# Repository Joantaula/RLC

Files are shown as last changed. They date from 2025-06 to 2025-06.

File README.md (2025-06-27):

# Cointer

Sistema clasificador con detección de falsificaciones y dispensado óptimo de cambio. Desarrollado como proyecto para la asignatura de Ingeniería Informática, Robótica.

---

## 📋 Descripción

Cointer es una solución robótica integral diseñada para automatizar el proceso de recepción y devolución de monedas en nuestros hogares a modo de hucha y en sistemas de pago físicos. El robot está formado por un módulo de detección por visión y pesaje, que identifica hasta ocho tipos de moneda (2 €, 1 €, 0,50 €, 0,20 €, 0,10 €, 0,05 €, 0,02 € y 0,01 €) determina si se trata de una moneda de euro o no. En caso negativo la descarta y en caso de ser una moneda de euro auténtica, la clasifica automáticamente segun su valor. Seguidamente, calcula en tiempo real el importe depositado. En caso de que el usuario solicite la extracción de un importe, un algoritmo voraz determina la combinación óptima de monedas para devolver el cambio exacto; si no es posible, se recurre a una rutina de respaldo que ajusta la selección.

El hardware integra una Raspberry Pi para la parte de visión y control de alto nivel, junto con un Arduino y hasta ocho motores paso a paso (uno por denominación) manejados por drivers A4988 o ULN2003 para el dispensado mecánico. La parte de software está estructurada en módulos: Monedero, para la lógica de cálculo y gestión de inventario de monedas, y Motores, para el control preciso de cada actuador. Además, un teclado matricial y una pantalla LCD permiten la interacción con el usuario, mostrando saldos, importes y estados del proceso.

Este proyecto combina conocimientos de electrónica, mecánica, visión artificial y diseño de algoritmos para ofrecer un sistema escalable, modular y fiable, ideal para administrar pequeños ahorros en el hogar y aplicaciones en máquinas expendedoras, kioscos de autoservicio y cualquier entorno que requiera gestión automática de monedas.

---

## 📊 Lista de componentes y presupuesto

| Componente | P. unitario (€) | Cantidad | Subtotal (€) |
| --- | ---:| ---:| ---:|
| Raspberry Pi 4 Model B 8 GB RAM | 88,55 | 1 | 88,55 |
| Cámara Raspberry Pi v2 – 8 Megapixels | 19,95 | 1 | 19,95 |
| Pantalla LCD 16×2 con módulo I²C | 7,95 | 1 | 7,95 |
| Motor paso a paso 28BYJ-48 (5 V) con driver ULN2003 | 2,95 | 10 | 29,50 |
| Arduino Mega2560 | 43,75 | 1 | 43,75 |
| Teclado matricial de 16 botones | 5,50 | 1 | 5,50 |
| Memoria MicroSD Kingston 128 GB (Clase 10) | 10,70 | 1 | 10,70 |
| Célula de carga 5 kg con amplificador HX711 | 4,10 | 1 | 4,10 |
| Fuente alimentación 4 salidas 5/12/−5/−12 125 W | 38,50 | 1 | 38,50 |
| **Total** | | | **248,5** |

> Consulta `Cointer_RLP_Budget 2.xlsx` para detalles de proveedores, enlaces y fechas de pedido.

---

## ⚙️ Características

- **Lectura de saldo**: muestra por Serial el total de euros disponible.  
- **Entrada de importe**: teclado matricial 4×4 para introducir cantidades con coma (‘*’).  
- **Algoritmo de cambio**: voraz con respaldo y reversión si no hay cambio exacto.  
- **Dispensado**: control de hasta 8 motores paso a paso (uno por cada denominación).  
- **Modularidad**: separa lógica de cálculo de cambio (Monedero) y control de motores (Motores).
- **Escalabilidad**: fácil adaptación a nuevas denominaciones o mecanismos de dispensado mediante configuración de Monedero y mapeo de motores.

---

## 📦 Estructura de ficheros

```text
/  
├─ designs
│   ├─ disseny3D.pdf
│   ├─ disseny3D.step
│   └─ esquema_conexiones.png
├─images
│   ├─ ....
├─ src
│   ├─ arduino
│   │   ├─ lcd.h
│   │   ├─ numpad.h 
│   │   ├─ Monedero.h
│   │   ├─ Monedero.cpp       
│   │   ├─ Motores.h          
│   │   ├─ Motores.cpp        
│   │   ├─ ControlDineroCompleto.ino
|   |   ├─ Testers
|   |   |    ├─ (Código testing componentes)
|   ├─ raspberry
|   |   ├─ Neural_Network
|   |   |   ├─ classify_image.py
|   |   |   ├─ preprocess_image.py
|   |   |   ├─ train_model.py
|   |   ├─  Testers
|   |   |   ├─ (Código testing componentes)
|   |   ├─ config.py
|   |   ├─ main.py
|   |   ├─ motor.py
|   |   ├─ sensor_peso.py
|   |   └─ vision.py
├─ Cointer_RLP_Budget 2.xlsx   # Presupuesto detallado
└─ README.md       
```

## 🛠️ Instalación y compilación
Abre el proyecto en el Arduino IDE (y en VS Code/Thonny para Pi, si lo usas).

Instala la librería Keypad desde el Gestor de Bibliotecas.

Copia los archivos .h, .cpp, el .ino y el .xlsx en la misma carpeta de sketch/repositorio.

Selecciona placa y puerto correctos.

Compila y sube al Arduino; en el Pi, lanza el script de visión si corresponde.

## 📚 Referencias y guías

(Todos los enlaces revisados antes del 25/06/2025)

Para facilitar el montaje y uso de los componentes hardware, se recomienda consultar las siguientes guías y documentación oficiales: [Especificaciones de la Raspberry Pi 4 Model B 8 GB RAM](https://www.raspberrypi.com/products/raspberry-pi-4-model-b/specifications/), [SparkFun HX711 Load Cell Amplifier Hookup Guide](https://learn.sparkfun.com/tutorials/load-cell-amplifier-hx711-breakout-hookup-guide/all), [Documentación de la cámara Raspberry Pi Camera Module V2](https://www.raspberrypi.com/documentation/accessories/camera.html), [Tutorial Arduino LCD 20×4 I²C](https://arduinogetstarted.com/tutorials/arduino-lcd-20x4), [Tutorial 28BYJ-48 + ULN2003](https://m.youtube.com/watch?v=avrdDZD7qEQ), [Especificaciones NEMA 8 en STEPPERONLINE](https://www.omc-stepperonline.com/nema-8-stepper-motor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), [Datasheet Luxeon III (LED RGB 3 W) en Farnell](https://www.farnell.com/datasheets/38512.pdf), [SparkFun Qwiic Keypad Hookup Guide](https://learn.sparkfun.com/tutorials/qwiic-keypad-hookup-guide/all), [Documentación Raspberry Pi Pico](https://www.raspberrypi.com/documentation/microcontrollers/raspberry-pi-pico.html), [Datasheet microSDHC/microSDXC Class 10 UHS-I (128 GB) de Kingston](https://www.kingston.com/datasheets/SDC10G2_us.pdf), [A4988 Stepper Motor Driver Carrier – Pololu #1182](https://www.pololu.com/product/1182) y [MPB125-4350G AC-DC 4 salidas 125 W de Bel Fuse](https://www.belfuse.com/products/power-supplies/ac-dc-converters/mpb125-4350g).

# Estructura del robot
## Tambor
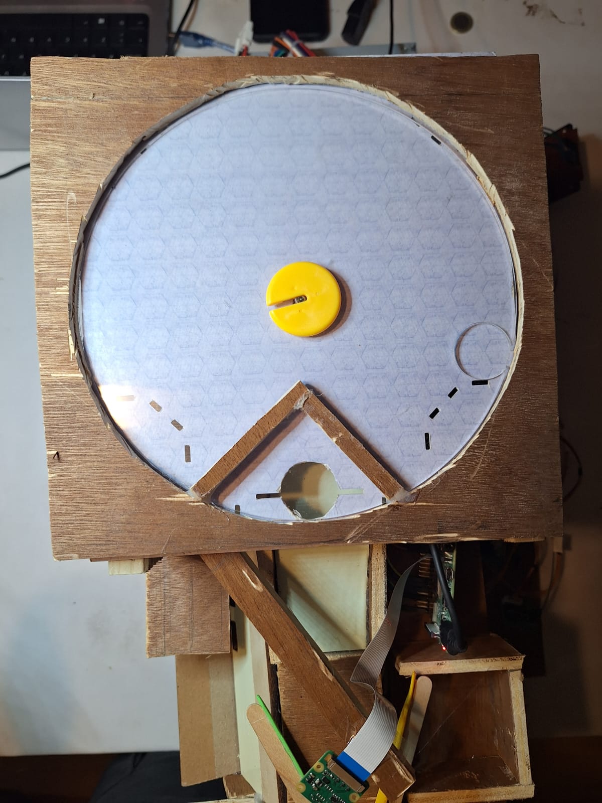
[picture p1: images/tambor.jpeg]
Tambor

Esta es la parte donde se inicializa el funcionamiento del robot. Se colocan el conjunto de monedas a clasificar encima del tambor, este tiene un funcionamiento parecido al de un tambor alimentario, que al rotar, empuja las monedas hacia las paredes de manera que una de las monedas entra en la muesca (de diámetro y altua de una moneda de 2 euros) en el tambor. Una vez da la vuelta es la única moneda capaz de sobrepasar las paredes de madera que delimitan el abujero y cayendo en este y deslizandose por la rampa hasta el sensor de peso.
## Discriminador
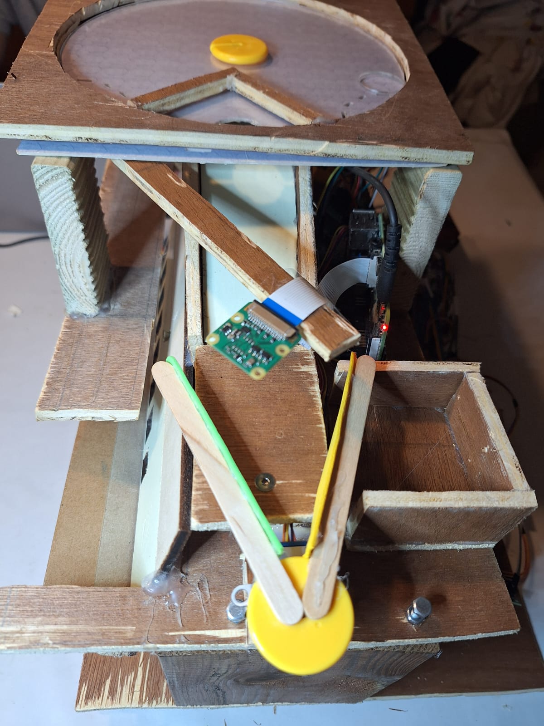
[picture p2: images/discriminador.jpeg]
Discriminador

Una vez la moneda ha caído por la rampa y se situa en el sensor de peso, la raspberry ordena la detención del motor paso a paso del tambor (usa multithreading, ya que va rotando el motor y va midiendo si hay una variación de peso en el sensor) y mediante la celula de carga se obtiene el peso del elemento que ha sido seleccionado y junto a la imagen capturada de la moneda en este momento mediante la camara de la raspberry, se procede a disriminar usando la red neuronal el objeto (moneda de euro o no). Una vez clasificado, se ordena al otro motor paso a paso a rotar para retirar la moneda del sensor de peso (si la rotación es en sentido horario, se descarta el objeto y se almacena en un pequeño compartimento al lado del sensor de peso. Rotación en sentido antihorario, la moneda cae en la rampa clasificadora) y seguir con el resto de clasificación.
## Clasificador
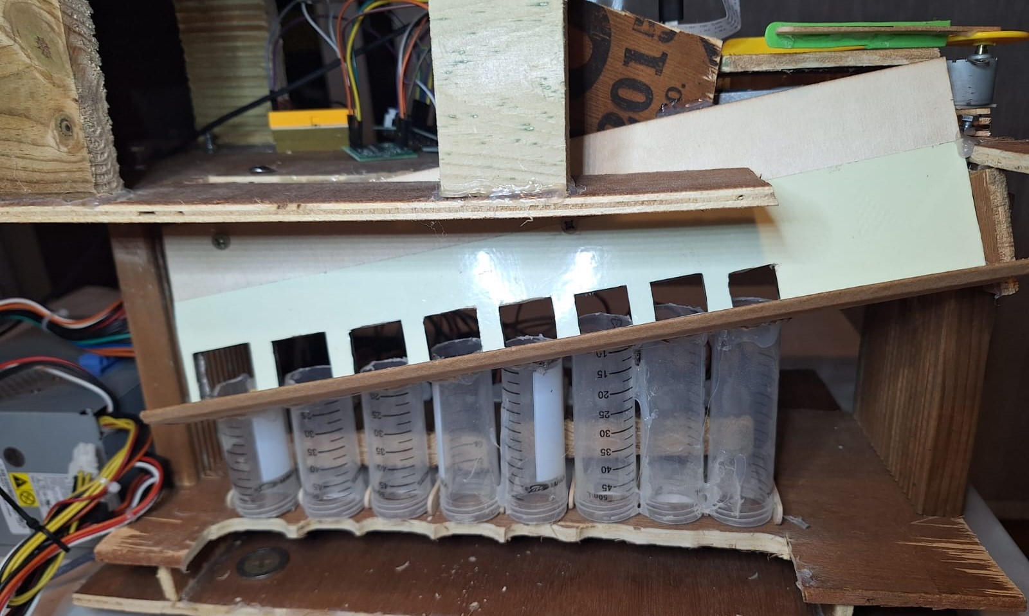
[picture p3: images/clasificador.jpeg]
Clasificador

Una vez sabemos que el objeto seleccionado es una moneda, esta cae sobre la rampa de clasificacion, rodando sobre el canto, y gracias a la inclinación tanto en eje x como en eje y, esta cojerá inercia y caerá en su respectivo compartimento, cayendo en el primer abujero que quepa. Teniendo en cuenta que para hacer esto los compartimentos se ordenan de menor a mayor diametro de la moneda (En orden ascendente de derecha a izquierda se ordenan: 1,2,10,5,20cnts,1€,50cnts,2€).
## Almacenamiento
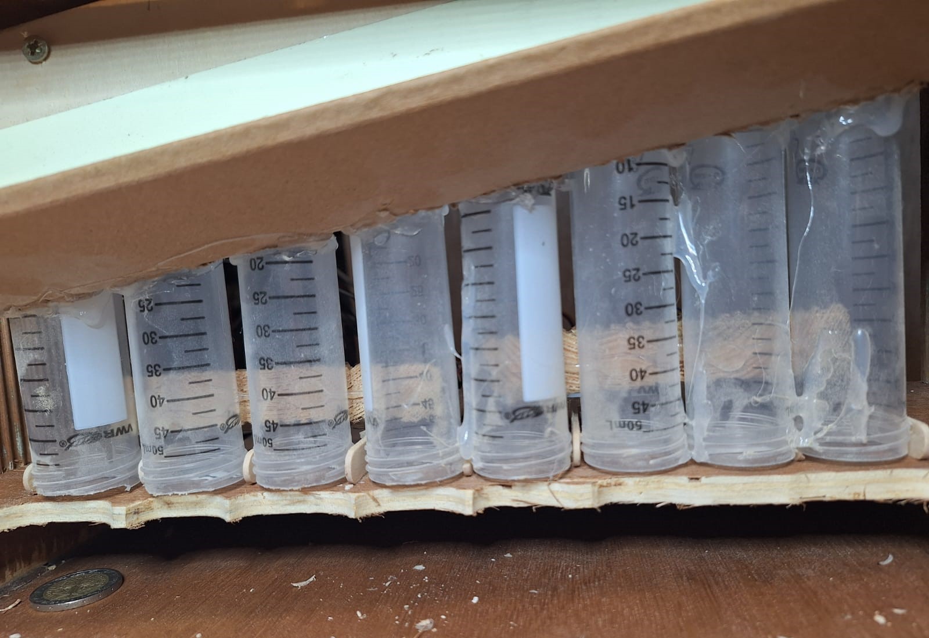
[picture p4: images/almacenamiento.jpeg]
Almacenamiento

A esta altura, la moneda ya habrá sido almacenada en el compartimento correspondiente, en cada uno de estos se admite un gran número de monedas que serán extraídas mediante los motores paso a paso, uno para cada tubo.
## Bielas
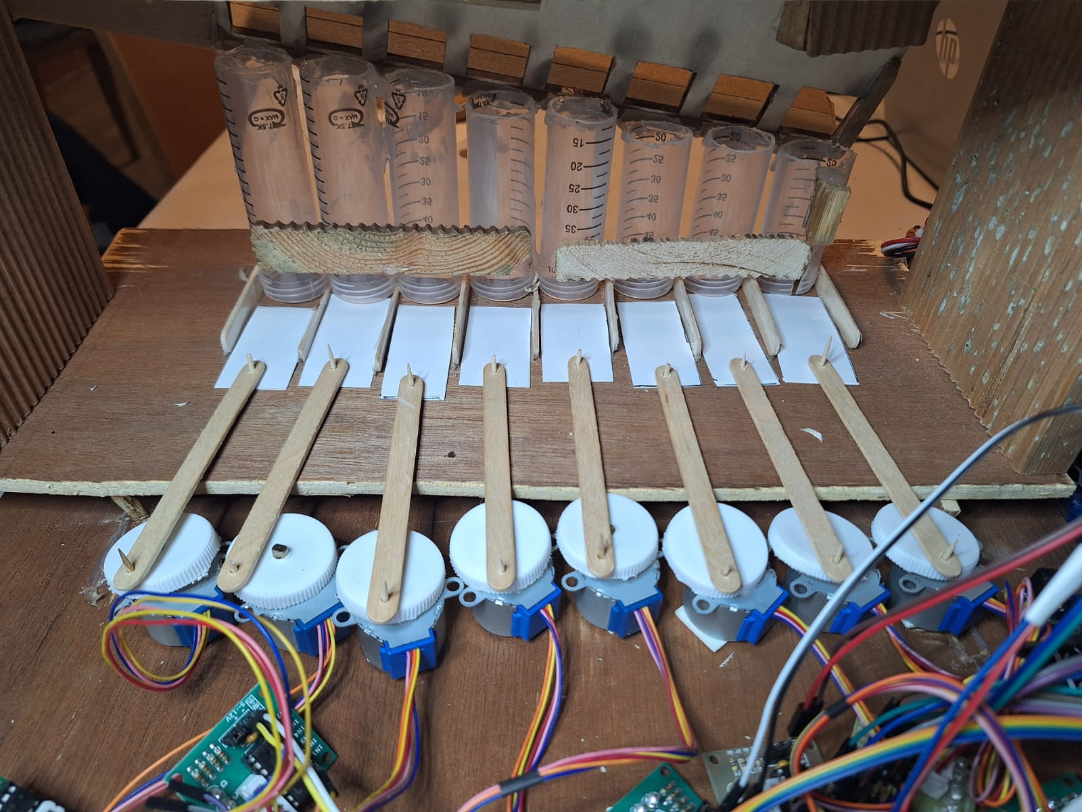
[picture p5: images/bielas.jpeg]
Bielas

Para dar pie a la extracción de una cantidad concreta de monedas, usaremos un arduino que se encargará de controlar los 8 motores paso a paso (1 para cada tipo de moneda). Cada motor paso a paso tiene unido una pieza que replica el funcionamiento de una biela manivela, de manera que cuando pedimos la extracción de una o varias monedas, el motor o motores paso a paso correspondientes emujan las monedas. Además con la separación que hay entre cada compartimento y el soporte permite que al empujar con la biela solo salga una moneda aún que en el compartimento se encuentre más de una.
## Numpad
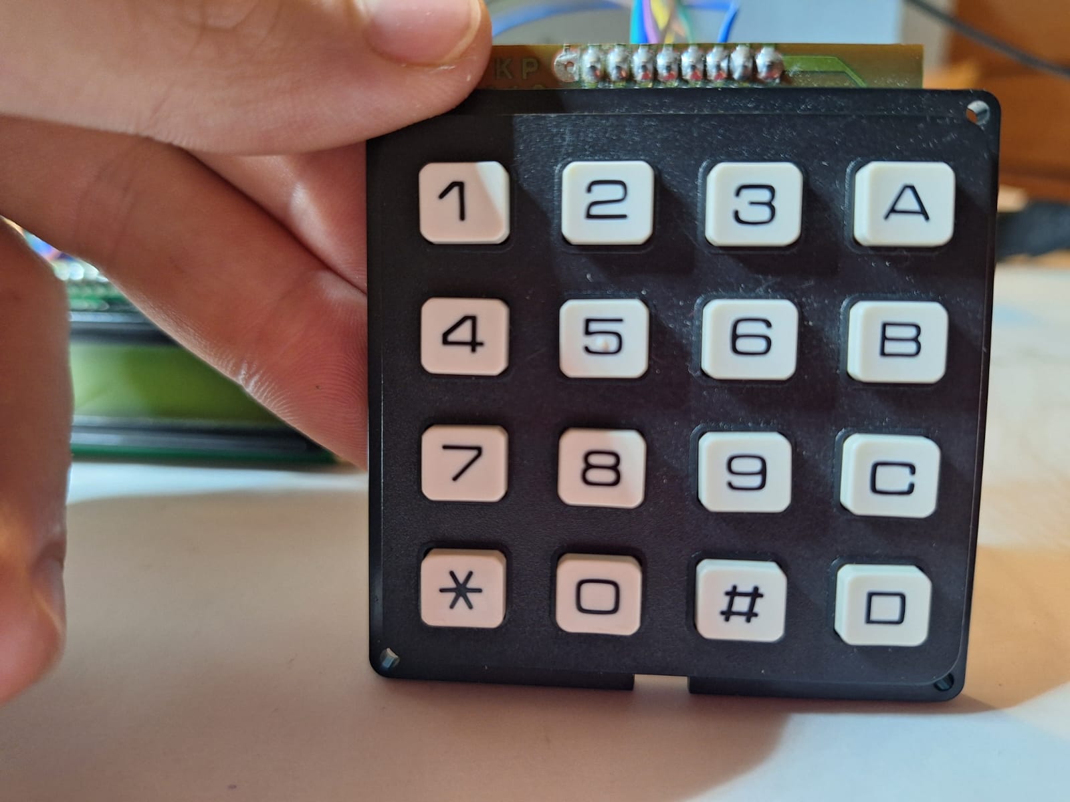
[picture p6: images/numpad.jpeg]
Numpad

Este es el componente mediante el que solicitaremos la extracción de un importe concreto (esta conectado al arduino). En el caso del numpad usado, antes de extraer un importe deberemos de presionar la tecla "#" y la coma se representa con el caracter "*". Una vez hemos indicado el importe deseado, presionaremos el caracter "C" para confirmar la dispensación. En caso de no querer confirmar la extracción del importe presionarmeos "B" para volver al menú inicial.
## Pantalla
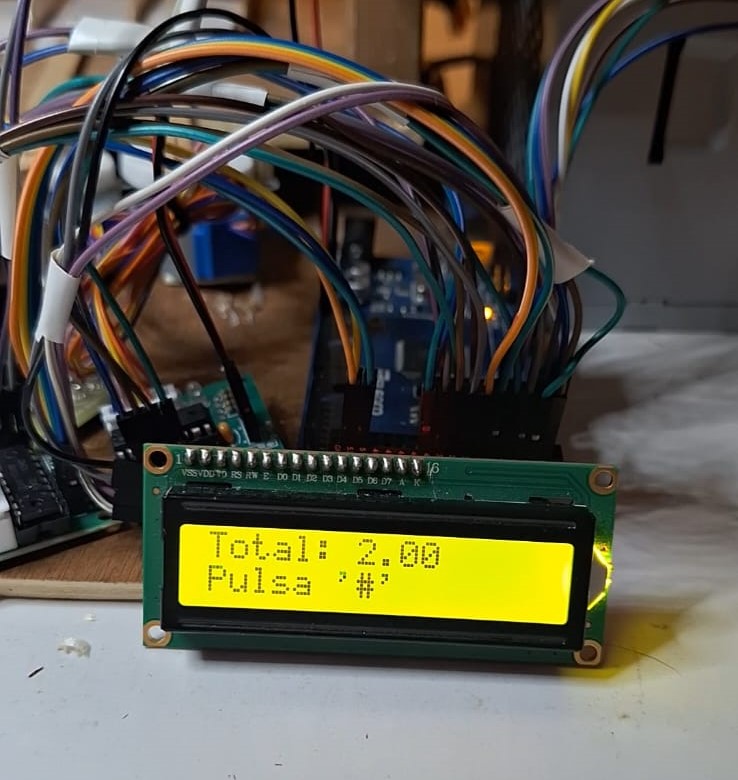
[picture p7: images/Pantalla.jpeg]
Pantalla

Componente encargado de mostrar por pantalla de forma visual al usuario el contenido y funcionamiento del robot. Inicialmente podremos observar el valor de monedas que se encuentra almacenado (este valor se modifica al clasficar una moneda como moneda de euro gracias a la camara y sensor de peso, este nuevo valor se lo comunica la raspberry al arduino). También podemos ver cuando se esta haciendo una extracció o cuando se intenta hacer de forma errónea, teniendo sus respectivos errores explicativos (demasiados decimales, mas de una coma, valor de extracción nulo, cantidad insuficiente).

# Red Neuronal
Este proyecto utiliza una red neuronal convolucional (CNN) entrenada para clasificar monedas entre 9 categorías:

- `1cent`, `2cent`, `5cent`, `10cent`, `20cent`, `50cent`, `1eur`, `2eur`, `no_coin`

### 📌 Propósito

La red neuronal se encarga de **clasificar automáticamente** la moneda capturada por la cámara al caer en el compartimento de pesaje. Según su clase, el sistema activa el motor correspondiente para enviar la moneda a su recipiente final o la rechaza si es falsa (`no_coin`).

---

### 🧱 Arquitectura del modelo

- Tipo: **Convolutional Neural Network (CNN)**
- Entrenamiento realizado con `TensorFlow/Keras`
- Input: imágenes de tamaño **128x128x3**
- Salida: capa softmax de 9 neuronas (una por clase)

**Resumen del modelo:**
Conv2D → MaxPooling2D → Conv2D → MaxPooling2D → Flatten → Dense → Dropout → Dense(9, softmax)
---

### 🧪 Dataset

- **Datos de entrenamiento:**  
  - Carpeta `Data_train/`  
  - Contiene subcarpetas por clase (`1eur/`, `2cent/`, `no_coin/`, etc.)

- **Tamaño aproximado del conjunto:**  
  - ~60 imágenes por clase  
  - Se aplicó **data augmentation** para compensar la escasez de datos.

---

### 🏋️‍♂️ Entrenamiento

- Librerías usadas:
  - `TensorFlow`, `Keras`, `Pillow`, `NumPy`
- Aumento de datos:
  - Rotación, zoom, flip horizontal y brillo
- Optimización:
  - Función de pérdida: `categorical_crossentropy`
  - Optimizer: `Adam`
  - Métrica: `accuracy`
- Número de épocas: **50**
- Early stopping usado para evitar sobreajuste

---

### 💾 Guardado del modelo

El modelo se guarda como un fichero: modelo_monedas.h5

Este fichero debe colocarse en la raíz del proyecto, junto a `main.py`.

---

### 📤 Inferencia

Durante la ejecución:

1. Se captura una imagen con `libcamera-still`
2. Se redimensiona a 128x128 y se normaliza
3. Se pasa al modelo para predecir la clase
4. Se usa la clase predicha para decidir la acción del motor

---

### 🧪 Precisión

- La red neuronal alcanza una precisión superior al **95%** en validación.
- El sistema es **invariante a rotación y escala** debido al uso de secciones locales de Fourier durante el preprocesado (si se implementa).
- Clasifica correctamente monedas no vistas si están dentro de las clases conocidas.

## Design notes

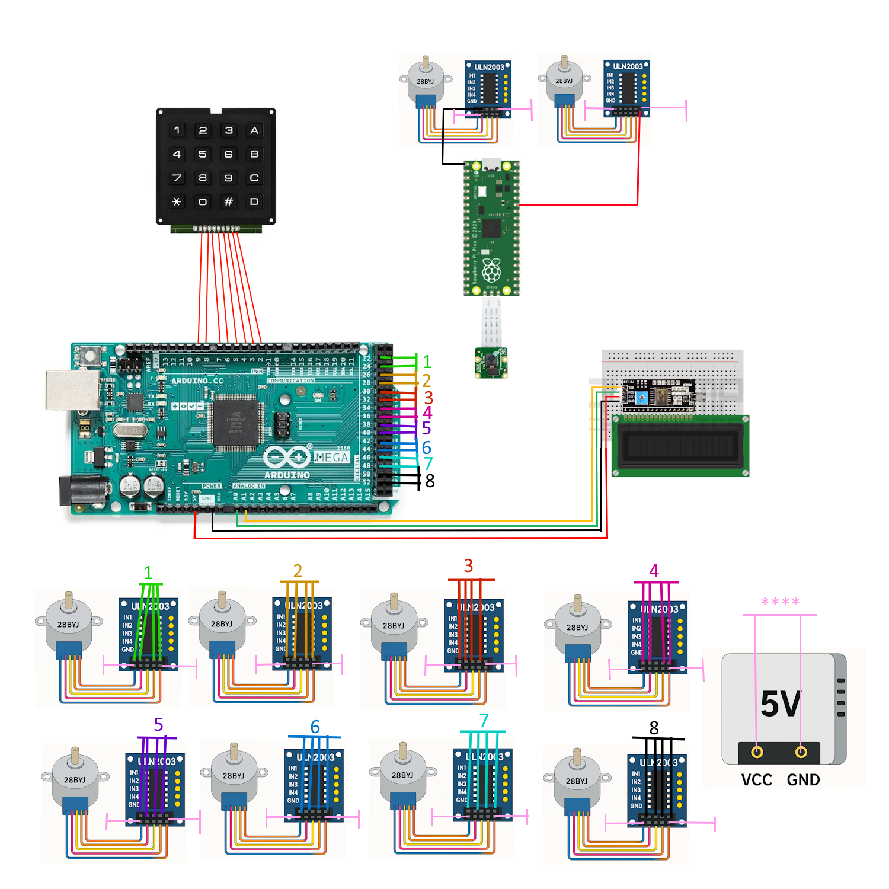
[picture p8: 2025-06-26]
designs/esquema_conexiones.png

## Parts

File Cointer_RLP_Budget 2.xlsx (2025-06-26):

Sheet: Bricogeek
Name | Price | Units | Total | URL
Raspberry pi 4 Modelo B 8GB ram | €88.55 | 1.00 | 88.5 | https://tienda.bricogeek.com/placas-raspberry-pi/1478-raspberry-pi-4-modelo-b-8gb-ram.html
I2C HX711 | €4.95 | 1.00 | €4.95 | https://tienda.bricogeek.com/sensores-y-actuadores/1984-m5stack-sensor-de-peso-i2c-hx711.html
Cámara Raspberry Pi v2 - 8 Megapixels | €19.95 | 1.00 | €19.95 | https://tienda.bricogeek.com/accesorios-raspberry-pi/822-camara-raspberry-pi-v2-8-megapixels.html
Pantalla LCD 20x4 con módulo i2C | €7.95 | 1.00 | €7.95 | https://tienda.bricogeek.com/pantallas-lcd/1828-pantalla-lcd-20x4-con-modulo-i2c.html
Motor paso a paso 28BYJ-48 (5V) con driver ULN2003 | €2.95 | 10.00 | €29.50 | https://tienda.bricogeek.com/motores-paso-a-paso/969-motor-paso-a-paso-28byj-48-5v-con-driver-uln2003.html
Motor paso a paso NEMA 8 - 180g/cm | €27.60 | 1.00 | €27.60 | https://tienda.bricogeek.com/motores/269-motor-paso-a-paso-nema-8-180gcm.html
LED Luxeon RGB 3W con base de aluminio | €5.90 | 1.00 | €5.90 | https://tienda.bricogeek.com/componentes/61-led-luxeon-rgb-3w-con-base-de-aluminio.html
Teclado Matricial de 12 botones | €5.50 | 1.00 | €5.50 | https://tienda.bricogeek.com/pulsadores-y-teclados/84-teclado-matricial-de-12-botones.html
Raspberry Pi Pico | €4.95 | 1.00 | €4.95 | https://tienda.bricogeek.com/placas-raspberry-pi/1513-raspberry-pi-pico.html
Memoria MicroSD Kingston 128GB (Clase 10) | €10.70 | 1.00 | €10.70 | https://tienda.bricogeek.com/accesorios-raspberry-pi/1760-memoria-microsd-kingston-128gb-clase-10-740617298703.html
Driver Pololu A4988 StepStick (Prusa / Reprap | €6.60 | 1.00 | €6.60 | https://tienda.bricogeek.com/controladores-motores/553-pololu-a4988-stepstick-prusa-reprap.html
Célula de carga 5Kg con amplificador HX711 | €4.10 | 1.00 | €4.10 | https://tienda.bricogeek.com/sensores-presion/1291-celula-de-carga-5kg-con-amplificador-hx711.html
TOTAL |  |  | 216.2

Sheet: Electan
Name | Price | Units | Total | URL
TOTAL |  |  | 0

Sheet: Farnell
Name | Price | Units | Total | URL
TOTAL |  |  | 0

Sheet: Diotronic
Name | Price | Units | Total | URL
FUENTA ALIMENTACION 4 SALIDAS 5/12/-5/-12 125W | €38.50 | 1.00 | €38.50 | https://diotronic.com/fuentes-en-caja/7152-f-a-4-salidas-5-12-5-12-125
TOTAL |  |  | €38.50

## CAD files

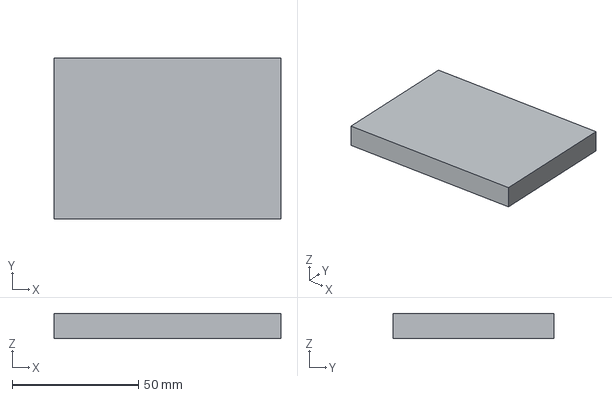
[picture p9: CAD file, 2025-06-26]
designs/disseny3D.step
90.0 x 64.0 x 10.0 mm

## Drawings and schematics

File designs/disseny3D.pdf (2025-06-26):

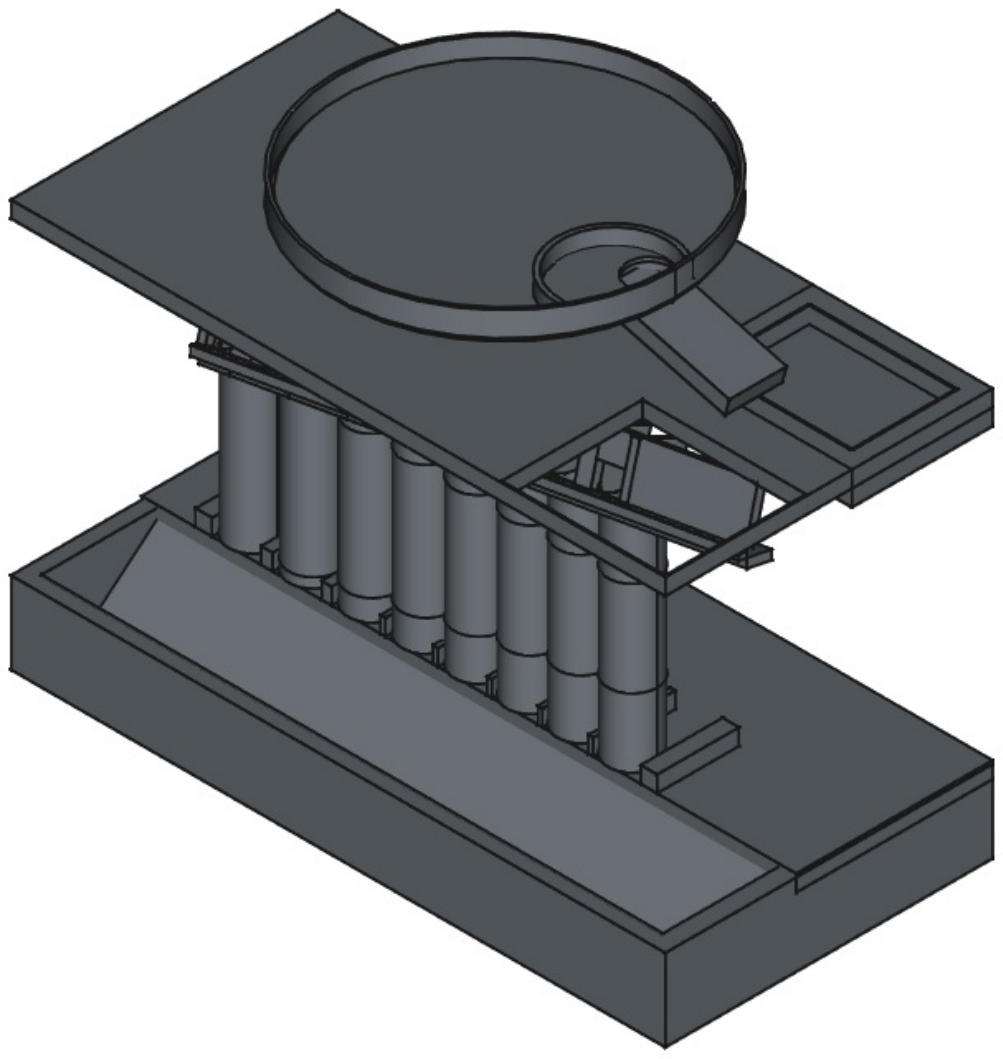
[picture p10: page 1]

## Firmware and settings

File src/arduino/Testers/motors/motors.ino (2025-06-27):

#include <AccelStepper.h>

// Definición de los 8 motores
AccelStepper motor1(AccelStepper::FULL4WIRE, 22, 24, 23, 25);
AccelStepper motor2(AccelStepper::FULL4WIRE, 30, 32, 31, 33);
AccelStepper motor3(AccelStepper::FULL4WIRE, 26, 28, 27, 29);
AccelStepper motor4(AccelStepper::FULL4WIRE, 34, 36, 35, 37);
AccelStepper motor5(AccelStepper::FULL4WIRE, 50, 52, 51, 53);
AccelStepper motor6(AccelStepper::FULL4WIRE, 38, 40, 39, 41);
AccelStepper motor7(AccelStepper::FULL4WIRE, 46, 48, 47, 49);
AccelStepper motor8(AccelStepper::FULL4WIRE, 42, 44, 43, 45);

// Array de punteros a motores
AccelStepper* motores[] = {
  &motor1, &motor2, &motor3, &motor4,
  &motor5, &motor6, &motor7, &motor8
};

const int numMotores = 8;
const int pasos = 200;        // Número de pasos por giro (ajusta según motor)
const int velocidad = 200;    // Pasos por segundo
const int aceleracion = 100;  // Aceleración en pasos/s²

void setup() {
  Serial.begin(9600);

  // Configurar todos los motores
  for (int i = 0; i < numMotores; i++) {
    motores[i]->setMaxSpeed(velocidad);
    motores[i]->setAcceleration(aceleracion);
  }

  Serial.println("Inicio del test de motores...");
}

void loop() {
  for (int i = 0; i < numMotores; i++) {
    Serial.print("Moviendo motor ");
    Serial.println(i + 1);

    motores[i]->moveTo(pasos);
    while (motores[i]->distanceToGo() != 0) {
      motores[i]->run();
    }

    delay(500);

    motores[i]->moveTo(0);  // Volver a la posición original
    while (motores[i]->distanceToGo() != 0) {
      motores[i]->run();
    }

    delay(1000);  // Pausa antes de pasar al siguiente motor
  }

  Serial.println("Test completo. Reiniciando en 5s...");
  delay(5000);
}

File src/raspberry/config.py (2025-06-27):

# Pines motores
motor1_pins = [4, 17, 27, 22]
motor2_pins = [5, 6, 13, 26]

# Pines HX711
DT_PIN = 19
SCK_PIN = 21
REFERENCE_UNIT = -408.43

# Tamaño entrada del modelo
IMG_SIZE = (128, 128)

# Nombre del modelo
MODEL_PATH = "modelo_monedas.h5"

# Clases del modelo
CLASES = ['1cent', '2cent', '5cent', '10cent', '20cent', '50cent', '1eur', '2eur', 'no_coin']

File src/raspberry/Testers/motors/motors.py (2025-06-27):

import RPi.GPIO as GPIO
import time

# Definición de pines
motor1_pins = [4, 17, 27, 22]
motor2_pins = [5, 6, 13, 26]

# Secuencia estándar de medio paso para un motor 28BYJ-48
seq = [
    [1, 0, 0, 0],
    [1, 1, 0, 0],
    [0, 1, 0, 0],
    [0, 1, 1, 0],
    [0, 0, 1, 0],
    [0, 0, 1, 1],
    [0, 0, 0, 1],
    [1, 0, 0, 1]
]

def setup_motor(pins):
    for pin in pins:
        GPIO.setup(pin, GPIO.OUT)
        GPIO.output(pin, 0)

def move_motor(pins, steps=512, delay=0.002, direction=1):
    for i in range(steps):
        for j in range(8):
            for pin in range(4):
                GPIO.output(pins[pin], seq[(j * direction) % 8][pin])
            time.sleep(delay)

def main():
    GPIO.setmode(GPIO.BCM)
    GPIO.setwarnings(False)

    setup_motor(motor1_pins)
    setup_motor(motor2_pins)

    try:
        print("Motor 1 adelante")
        move_motor(motor1_pins, steps=256, delay=0.002, direction=1)
        print("Motor 1 atrás")
        move_motor(motor1_pins, steps=256, delay=0.002, direction=-1)

        time.sleep(1)

        print("Motor 2 adelante")
        move_motor(motor2_pins, steps=256, delay=0.002, direction=1)
        print("Motor 2 atrás")
        move_motor(motor2_pins, steps=256, delay=0.002, direction=-1)

    finally:
        GPIO.cleanup()
        print("Limpieza de pines completada.")

if __name__ == "__main__":
    main()

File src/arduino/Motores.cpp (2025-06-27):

#include "Motores.h"

// Definición de los motores y posiciones
// Definición de los motores y posiciones
AccelStepper motor1(AccelStepper::FULL4WIRE, 22, 24, 23, 25);
AccelStepper motor2(AccelStepper::FULL4WIRE, 30, 32, 31, 33);
AccelStepper motor3(AccelStepper::FULL4WIRE, 26, 28, 27, 29);
AccelStepper motor4(AccelStepper::FULL4WIRE, 34, 36, 35, 37);
AccelStepper motor5(AccelStepper::FULL4WIRE, 50, 52, 51, 53);
AccelStepper motor6(AccelStepper::FULL4WIRE, 38, 40, 39, 41);
AccelStepper motor7(AccelStepper::FULL4WIRE, 46, 48, 47, 49);
AccelStepper motor8(AccelStepper::FULL4WIRE, 42, 44, 43, 45); 

const long posA = 0;
const long posB = 1024;

void configurarMotores() {
  AccelStepper* motores[] = {&motor1, &motor2, &motor3, &motor4, &motor5, &motor6, &motor7, &motor8};
  for (int i = 0; i < 8; i++) {
    motores[i]->setMaxSpeed(200);
    motores[i]->setSpeed(200);
    motores[i]->setAcceleration(10000);
  }
}

void moveMotors(int total_2eur, int total_1eur, int total_50cent, int total_20cent, int total_10cent, int total_5cent, int total_2cent, int total_1cent, float total) {
  motor1.moveTo(posB);
  motor2.moveTo(posB);
  motor3.moveTo(posB);
  motor4.moveTo(posB);
  motor5.moveTo(posB);
  motor6.moveTo(posB);
  motor7.moveTo(posB);
  motor8.moveTo(posB);

  float returned = 0;
  int returned_2eur = 0, returned_1eur = 0, returned_50cent = 0, returned_20cent = 0, returned_10cent = 0, returned_5cent = 0, returned_2cent = 0, returned_1cent = 0;

  while (returned < total) {
    if (returned_2eur < total_2eur) {
      if (motor1.distanceToGo() == 0) {
        if (motor1.currentPosition() == posB) {
          motor1.moveTo(posA);
        } else {
          returned += 2.0;
          returned_2eur++;
          motor1.moveTo(posB);
        }
      }
      motor1.run();
    }

    if (returned_1eur < total_1eur) {
      if (motor2.distanceToGo() == 0) {
        if (motor2.currentPosition() == posB) {
          motor2.moveTo(posA);
        } else {
          returned += 1.0;
          returned_1eur++;
          motor2.moveTo(posB);
        }
      }
      motor2.run();
    }

    if (returned_50cent < total_50cent) {
      if (motor3.distanceToGo() == 0) {
        if (motor3.currentPosition() == posB) {
          motor3.moveTo(posA);
        } else {
          returned += 0.5;
          returned_50cent++;
          motor3.moveTo(posB);
        }
      }
      motor3.run();
    }

    if (returned_20cent < total_20cent) {
      if (motor4.distanceToGo() == 0) {
        if (motor4.currentPosition() == posB) {
          motor4.moveTo(posA);
        } else {
          returned += 0.2;
          returned_20cent++;
          motor4.moveTo(posB);
        }
      }
      motor4.run();
    }

    if (returned_10cent < total_10cent) {
      if (motor5.distanceToGo() == 0) {
        if (motor5.currentPosition() == posB) {
          motor5.moveTo(posA);
        } else {
          returned += 0.1;
          returned_10cent++;
          motor5.moveTo(posB);
        }
      }
      motor5.run();
    }

    if (returned_5cent < total_5cent) {
      if (motor6.distanceToGo() == 0) {
        if (motor6.currentPosition() == posB) {
          motor6.moveTo(posA);
        } else {
          returned += 0.05;
          returned_5cent++;
          motor6.moveTo(posB);
        }
      }
      motor6.run();
    }

    if (returned_2cent < total_2cent) {
      if (motor7.distanceToGo() == 0) {
        if (motor7.currentPosition() == posB) {
          motor7.moveTo(posA);
        } else {
          returned += 0.02;
          returned_2cent++;
          motor7.moveTo(posB);
        }
      }
      motor7.run();
    }

    if (returned_1cent < total_1cent) {
      if (motor8.distanceToGo() == 0) {
        if (motor8.currentPosition() == posB) {
          motor8.moveTo(posA);
        } else {
          returned += 0.01;
          returned_1cent++;
          motor8.moveTo(posB);
        }
      }
      motor8.run();
    }
  }
}

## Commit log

2025-06-26 Diseños 3D
    [disseny3D.step]
2025-06-26 excel con precios
    [Cointer_RLP_Budget 2.xlsx]
2025-06-27 Arduino module uploaded
    [disseny3D.step]
2025-06-27 Module Raspberry uploaded
